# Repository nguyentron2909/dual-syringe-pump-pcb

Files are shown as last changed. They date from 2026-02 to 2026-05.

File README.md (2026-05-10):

# Dual Syringe Pump Controller (ESP32 + TMC2209)

This repository contains the KiCad hardware design for a compact, battery-powered dual stepper motor controller. Designed around the **ESP32-WROOM-32** for wireless control and **TMC2209** silent stepper drivers, this board is optimized for high-precision multi-channel micropump systems and drug delivery applications.

## 🛠 Hardware Architecture

The project is divided into three main functional blocks:

### 1. Power Management & Charging
A robust power subsystem designed to handle both wall power and battery operation, ensuring uninterrupted dispensing.
* **Charging:** Integrated **TP5100** battery charger for 2S Li-ion setups.
* **Regulation:** * **Buck Converter (LM2596):** Stepping down input voltage to 5V for logic.
    * **LDO (AMS1117-3.3):** Providing stable 3.3V for the ESP32 and sensors.
    * **Dual Boost Converters (XL6009):** Independent 12V rails (`+12V_1` and `+12V_2`) to power the stepper drivers, allowing for high-torque performance even on battery power.

### 2. Main Control & Interface
The logic center of the board, featuring:
* **MCU:** ESP32-WROOM-32 with USB-C programming via **CH340C** and an auto-reset circuit.
* **Position Feedback:** Support for dual **AS5600** magnetic encoders via I2C for closed-loop monitoring and exact position tracking.
* **User Interface:** Headers for an external screen, status LEDs, and additional tactile buttons.

### 3. Stepper Driver Stage
High-performance motor control featuring:
* **Drivers:** Dual **TMC2209-LA** drivers (U6 & U7).
* **Communication:** UART interface mapped to the ESP32 for advanced configuration (StealthChop, StallGuard, dynamic current limits).
* **Optimization:** Support for hardware-level current sensing. *(Note: RS resistors should be desoldered from the current sensing module for better performance, as noted in the schematic).*

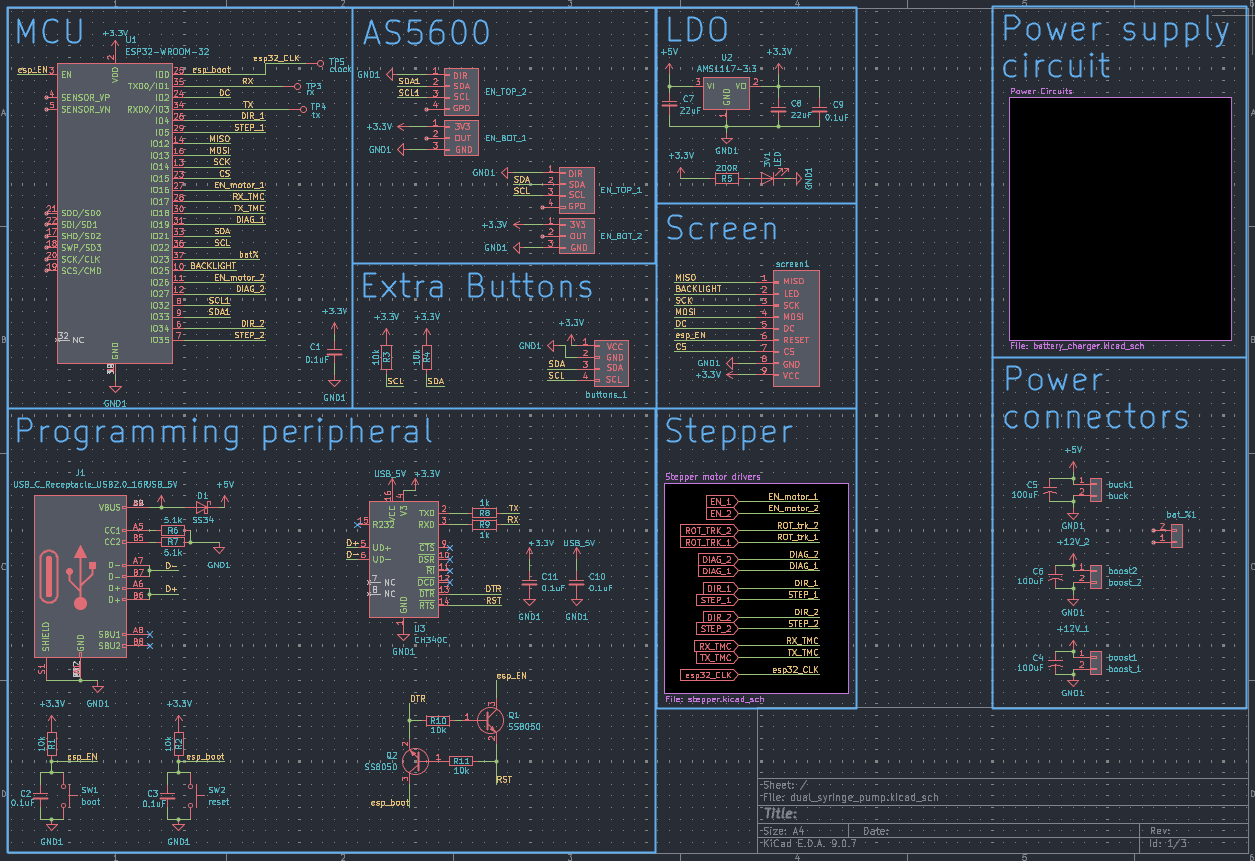
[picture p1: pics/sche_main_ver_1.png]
Control schematics

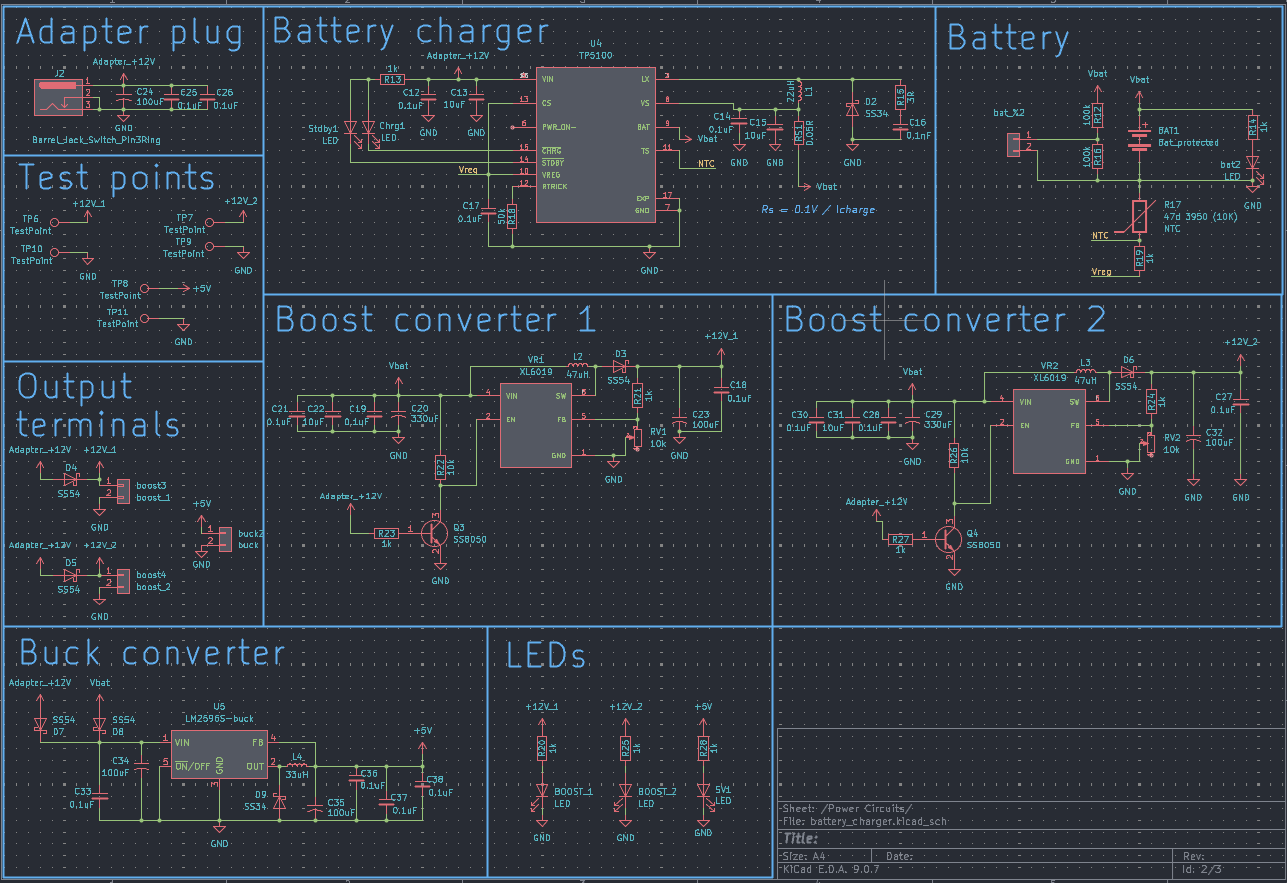
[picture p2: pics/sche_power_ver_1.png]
Power circuits

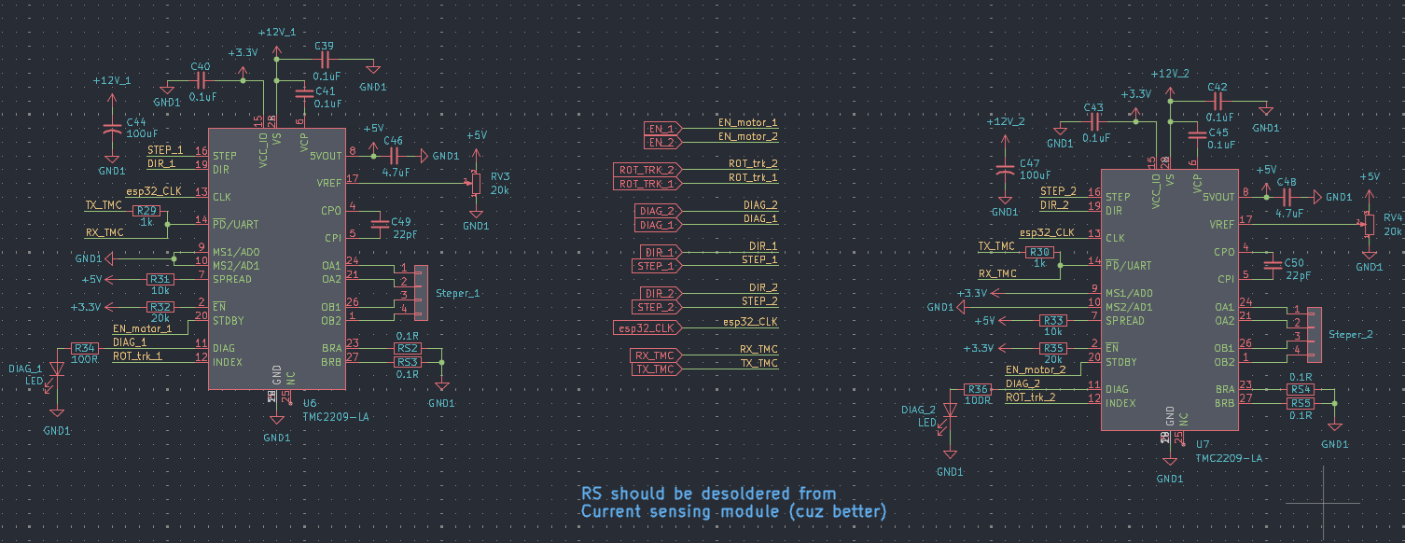
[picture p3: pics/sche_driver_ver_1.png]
drivers

---

## 📋 Key Specifications

| Component | Specification |
| :--- | :--- |
| **Microcontroller** | ESP32-WROOM-32 (Wi-Fi/BT) |
| **Stepper Drivers** | 2x TMC2209 (SilentStepStick style) |
| **Input Voltage** | +12V Adapter or 2S Li-ion Battery |
| **Logic Voltage** | 3.3V and 5V |
| **Sensors** | 2x AS5600 Magnetic Encoders |
| **USB Interface** | USB-C (CH340C) |

---

## 📂 PCB layout
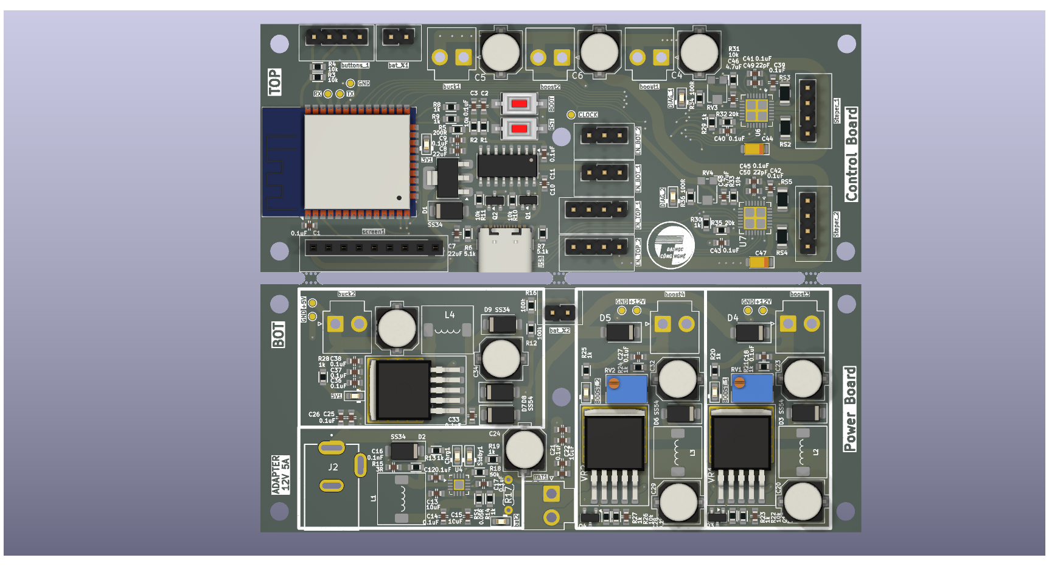
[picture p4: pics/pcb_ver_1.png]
PCB layout

---

## 📝 Design Notes

* **Current Sensing:** Ensure you desolder the RS resistors from the driver modules if you are using an external current sensing setup to avoid interference.
* **Thermal Management:** Provide adequate cooling (heatsinks/airflow) for the XL6009 boost converters and TMC2209 drivers if running the stepper motors at high continuous currents.
* **Big thanks to google gemini for writting this for me :D

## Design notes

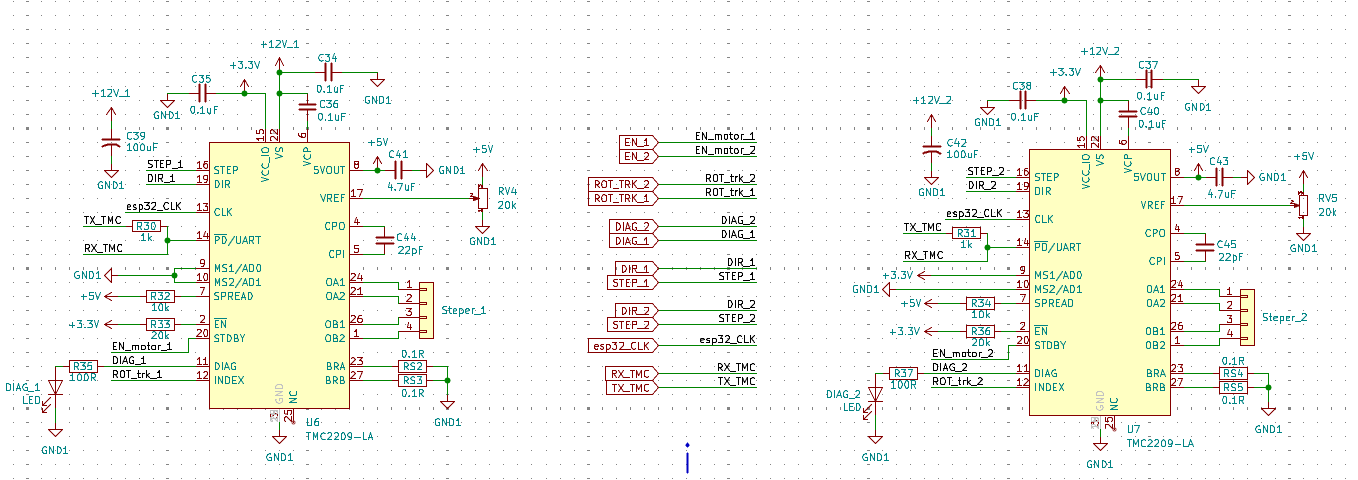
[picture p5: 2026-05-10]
pics/Screenshot 2026-04-07 160638.png

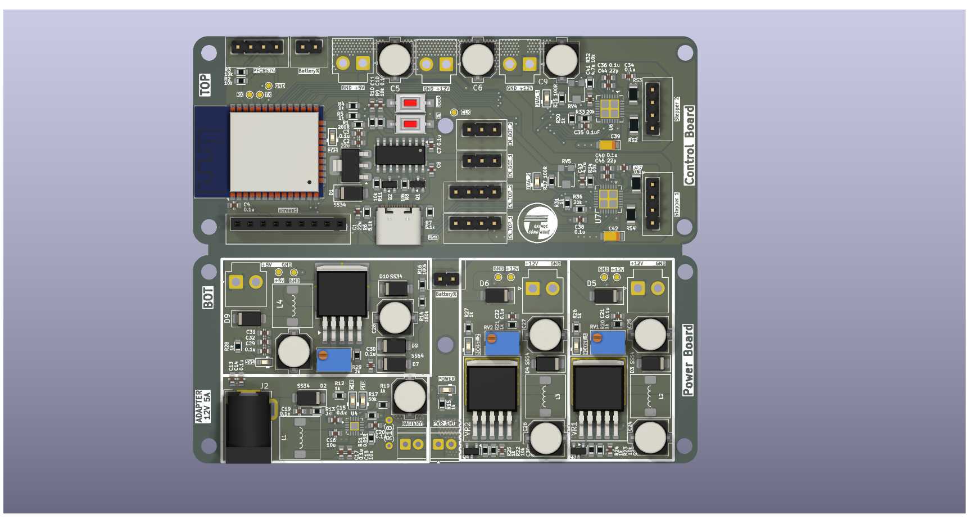
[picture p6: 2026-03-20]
pics/pcb_ver_2.png

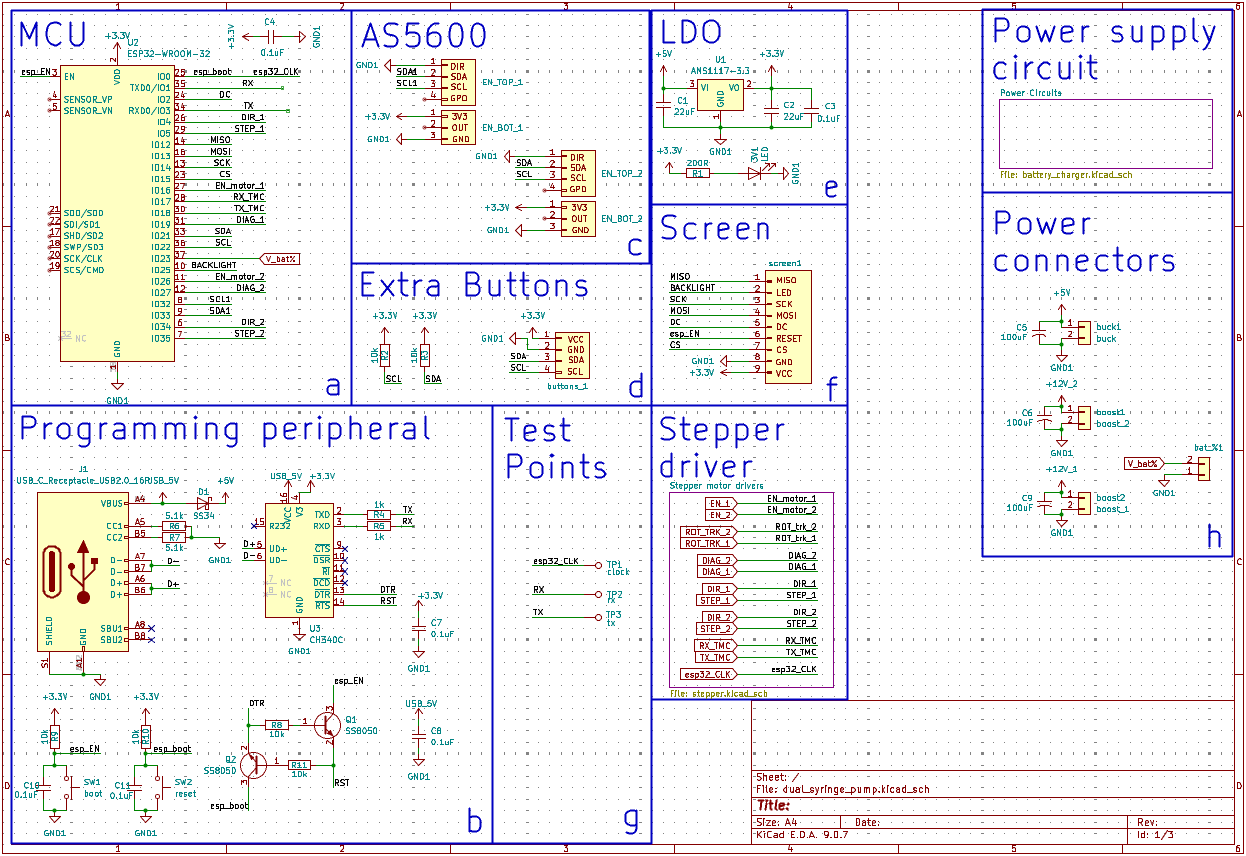
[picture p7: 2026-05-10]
pics/Screenshot 2026-04-07 160020.png

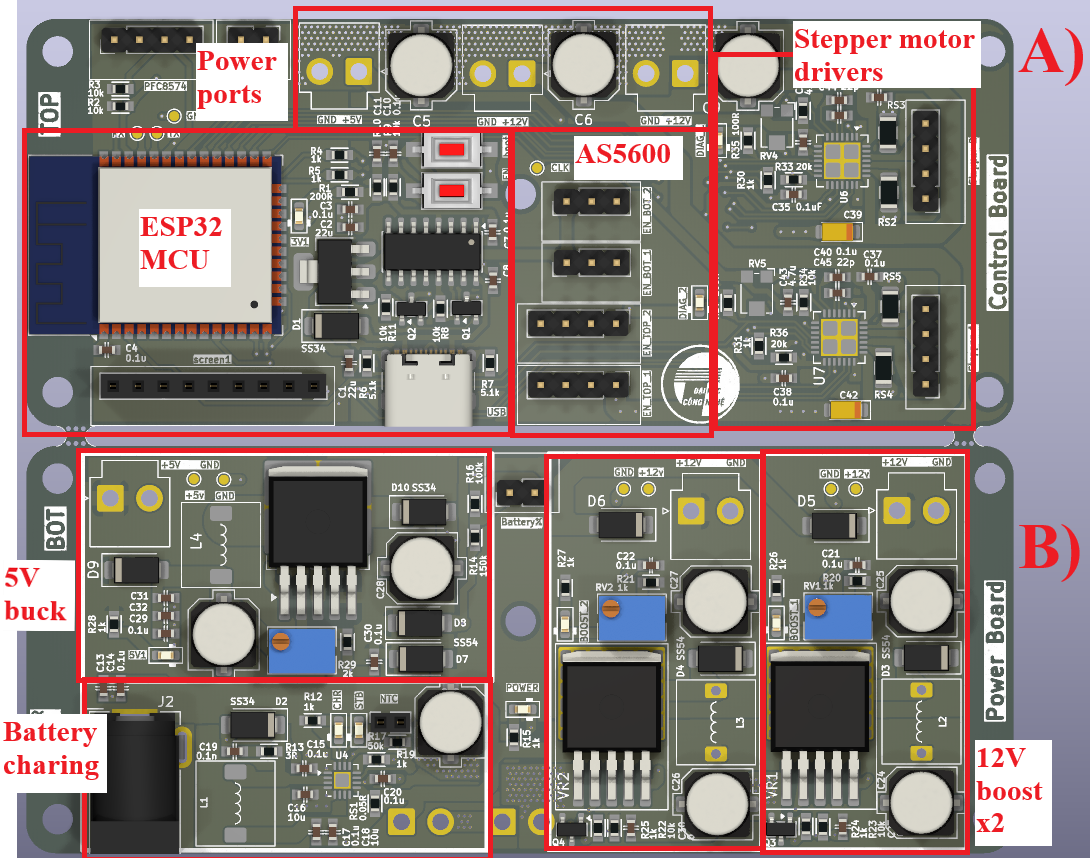
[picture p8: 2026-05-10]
pics/dual_syringe_pump.png

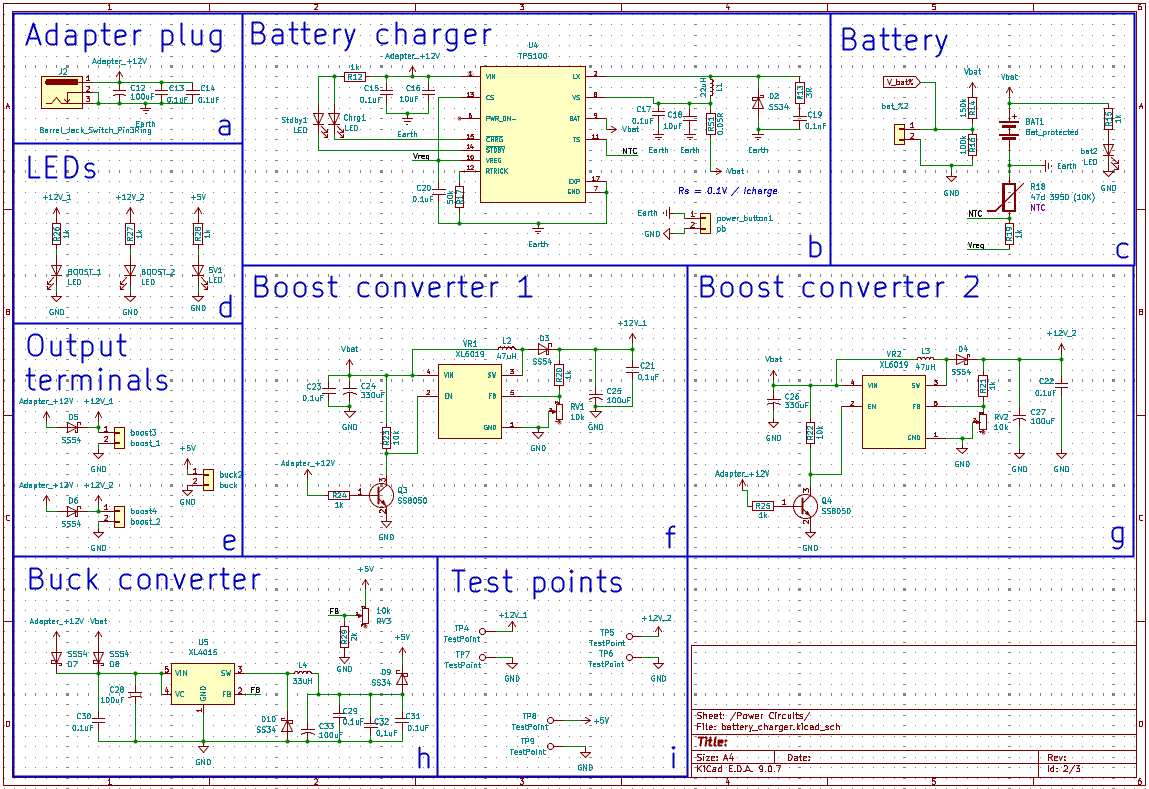
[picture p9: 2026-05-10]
pics/Screenshot 2026-04-07 150947.png

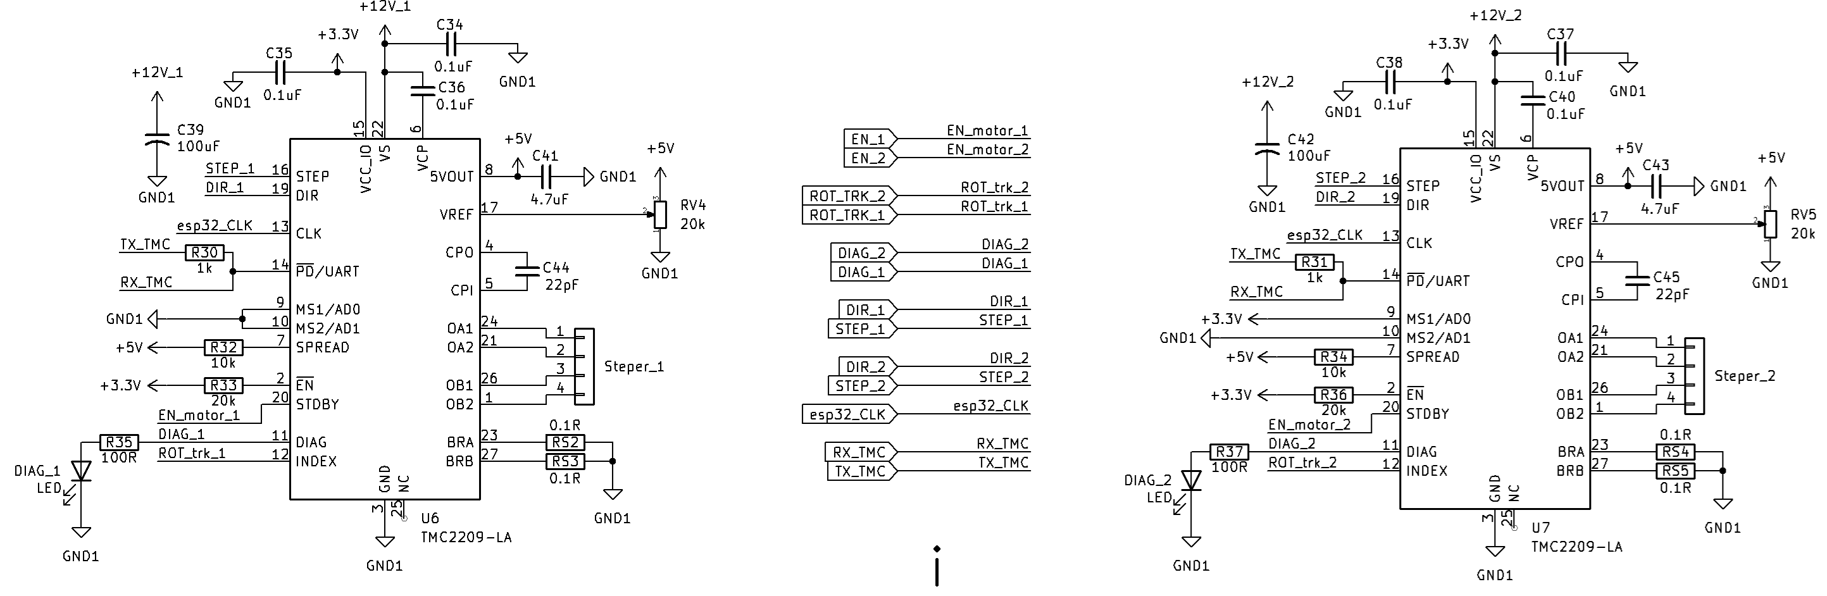
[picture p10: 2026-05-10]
pics/bruh.png

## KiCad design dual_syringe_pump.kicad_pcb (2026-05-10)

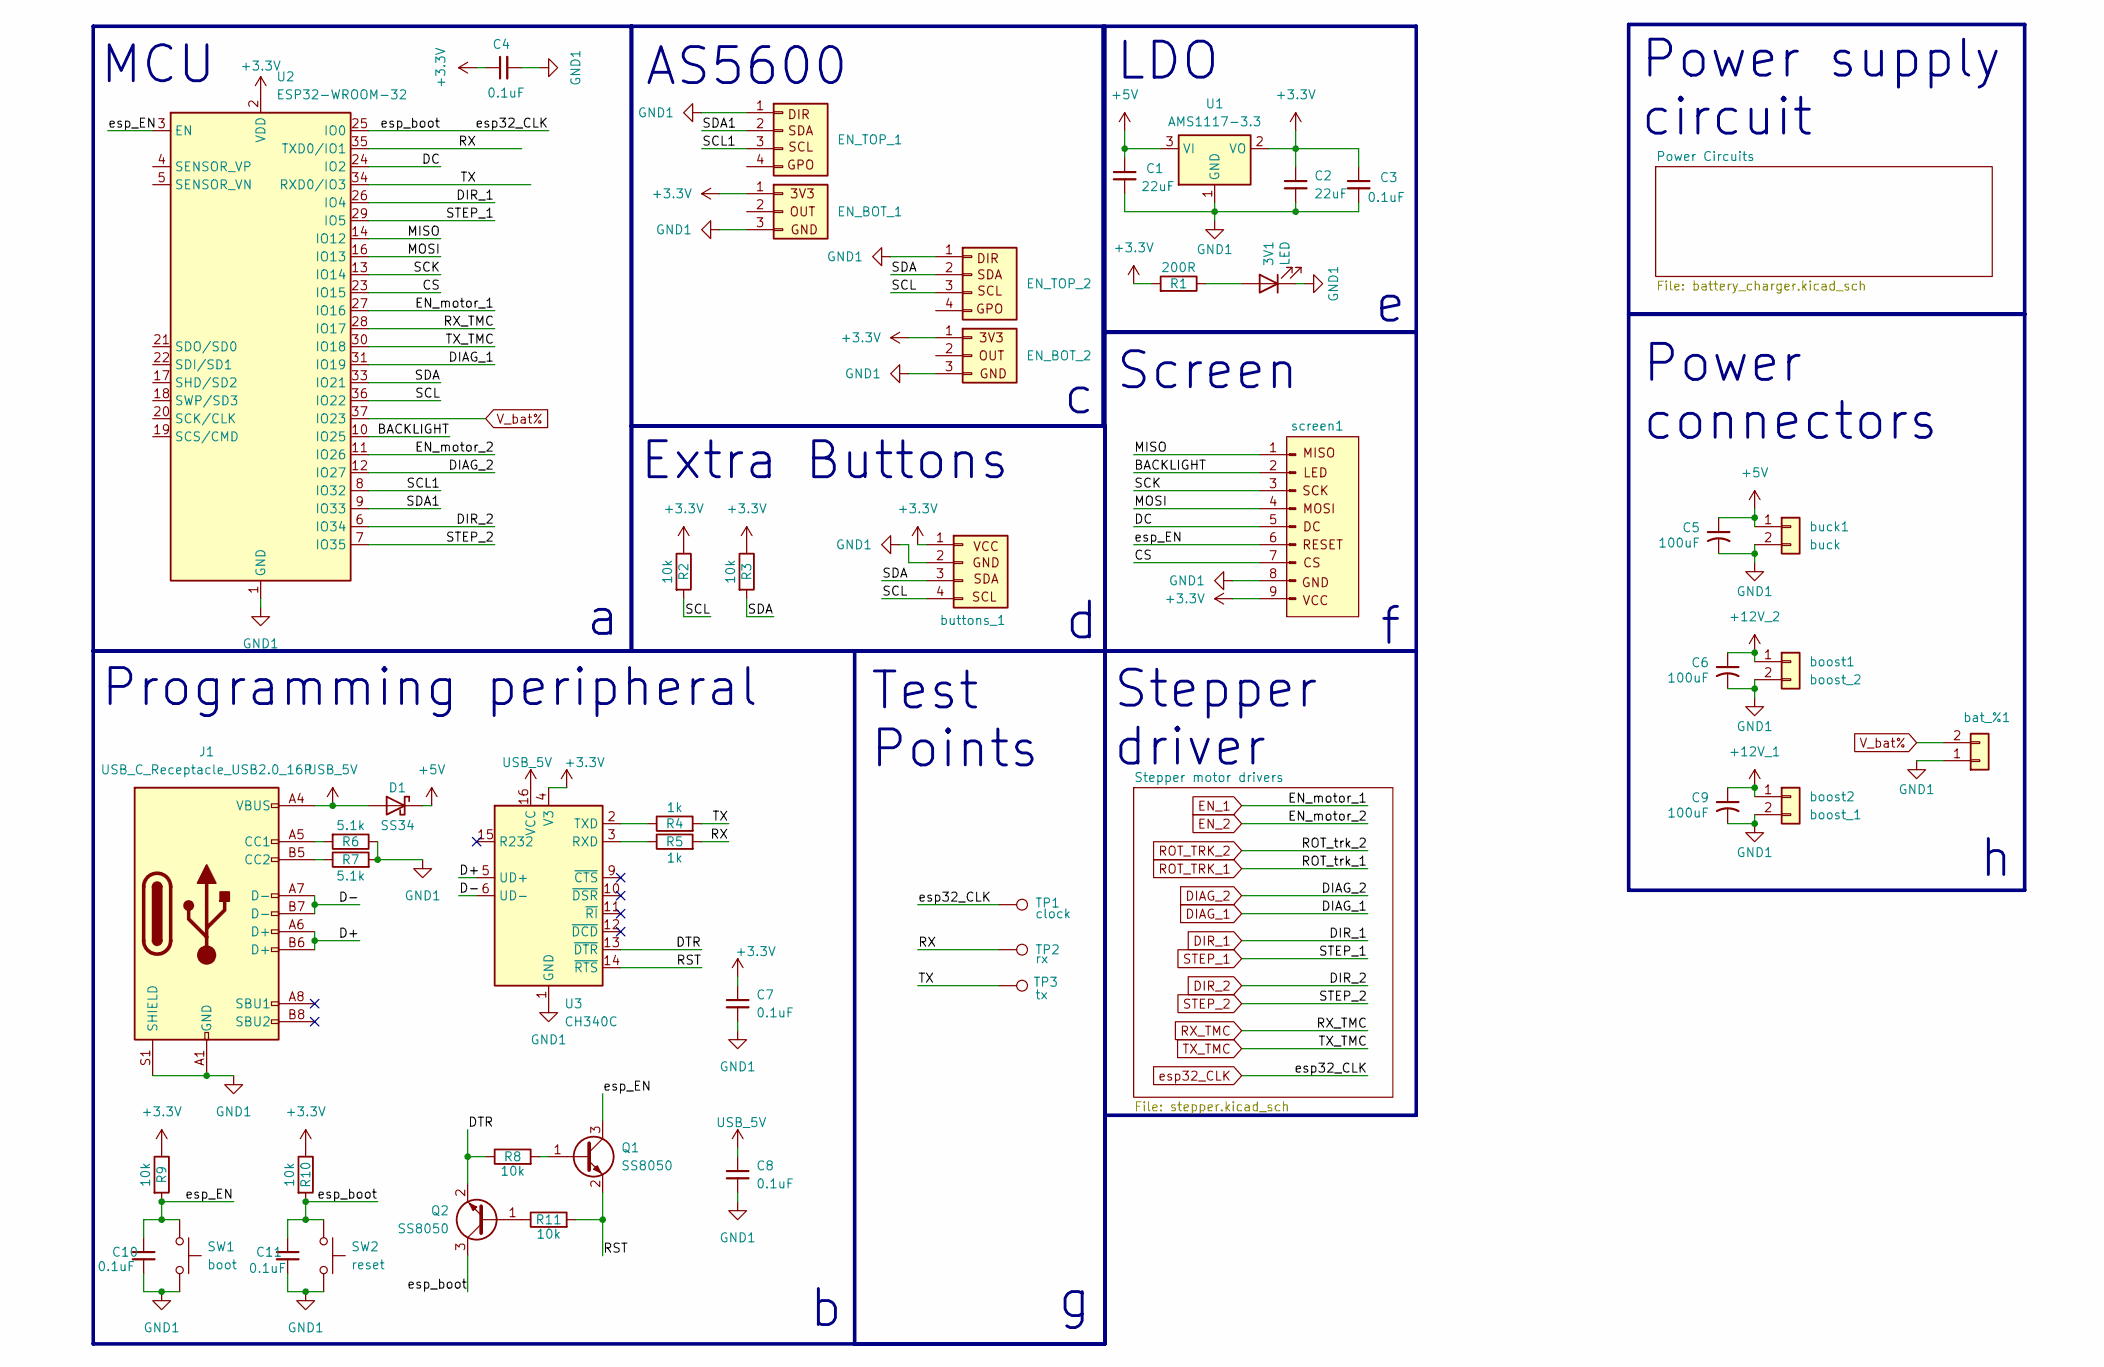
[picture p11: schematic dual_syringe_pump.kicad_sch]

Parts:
3V1: LED; LED_0603_1608Metric_Pad1.05x0.95mm
C1, C2: 22uF; C_0603
C3, C4, C7, C8, C10, C11: 0.1uF; C_0603
C5, C6, C9: 100uF; C_Elec_6.3x7.7
D1: SS34; D_SMA
EN_BOT_1, EN_BOT_2: Conn_01x03; PinHeader_1x03_P2.54mm_Vertical
EN_TOP_1, EN_TOP_2: Conn_01x04; PinHeader_1x04_P2.54mm_Vertical; Part Number 1-0401FBV0T
J1: USB_C_Receptacle_USB2.0_16P; USB_C_Receptacle_GCT_USB4105-xx-A_16P_TopMnt_Horizontal
Q1, Q2: SS8050; SOT-23
R1: 200R; R_0603
R2, R3, R8, R9, R10, R11: 10k; R_0603
R4, R5: 1k; R_0603
R6, R7: 5.1k; R_0603
SW1: boot; SW_SPST_CK_RS282G05A3
SW2: reset; SW_SPST_CK_RS282G05A3
TP1: clock; TestPoint_Pad_D1.0mm
TP2: rx; TestPoint_Pad_D1.0mm
TP3: tx; TestPoint_Pad_D1.0mm
U1: AMS1117-3.3; SOT-223-3_TabPin2
U2: ESP32-WROOM-32
U3: CH340C; SOIC-16_3.9x9.9mm_P1.27mm
bat_%1: battery _percentage; PinHeader_1x02_P2.54mm_Vertical; Part Number 1-0201FBV0T
boost1: boost_2; JST_VH_B2P-VH-B_1x02_P3.96mm_Vertical; Part Number 1-0201FBV0T
boost2: boost_1; JST_VH_B2P-VH-B_1x02_P3.96mm_Vertical; Part Number 1-0201FBV0T
buck1: buck; JST_VH_B2P-VH-B_1x02_P3.96mm_Vertical; Part Number 1-0201FBV0T
buttons_1: Conn_01x04; PinHeader_1x04_P2.54mm_Vertical; Part Number 1-0401FBV0T
screen1: Conn_01x09_Pin; PinSocket_1x09_P2.54mm_Vertical

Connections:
+3.3V: C2.1, C3.1, C4.1, C7.1, EN_BOT_1.1, EN_BOT_2.1, R1.2, R2.1, R3.1, R9.1, R10.1, U1.2 (VO), U2.2 (VDD), U3.4 (V3), buttons_1.1, screen1.9; also elsewhere on the board
+5V: C1.1, C5.1, D1.1 (K), U1.3 (VI), buck1.1; also elsewhere on the board
+12V_1: C9.1, boost2.1; also elsewhere on the board
+12V_2: C6.1, boost1.1; also elsewhere on the board
/BACKLIGHT: U2.10 (IO25), screen1.2
/CS: U2.23 (IO15), screen1.7
/D+: J1.A6 (D+), J1.B6 (D+), U3.5 (UD+)
/D-: J1.A7 (D-), J1.B7 (D-), U3.6 (UD-)
/DC: U2.24 (IO2), screen1.5
/DTR: Q2.2 (E), R8.1, U3.13 (~DTR)
/MISO: U2.14 (IO12), screen1.1
/MOSI: U2.16 (IO13), screen1.4
/RST: Q1.2 (E), R11.2, U3.14 (~RTS)
/RX: R5.2, TP2.1 (1_1), U2.35 (TXD0/IO1)
/SCK: U2.13 (IO14), screen1.3
/SCL: EN_TOP_2.3, R2.2, U2.36 (IO22), buttons_1.4
/SCL1: EN_TOP_1.3, U2.8 (IO32)
/SDA: EN_TOP_2.2, R3.2, U2.33 (IO21), buttons_1.3
/SDA1: EN_TOP_1.2, U2.9 (IO33)
/TX: R4.2, TP3.1 (1_1), U2.34 (RXD0/IO3)
/esp_EN: C10.1, Q1.3 (C), R9.2, SW1.1, U2.3 (EN), screen1.6
DIAG_1: U2.31 (IO19); also elsewhere on the board
DIAG_2: U2.12 (IO27); also elsewhere on the board
DIR_1: U2.26 (IO4); also elsewhere on the board
DIR_2: U2.6 (IO34); also elsewhere on the board
EN_1: U2.27 (IO16); also elsewhere on the board
EN_2: U2.11 (IO26); also elsewhere on the board
GND1: 3V1.1 (K), C1.2, C2.2, C3.2, C4.2, C5.2, C6.2, C7.2, C8.2, C9.2, C10.2, C11.2, EN_BOT_1.3, EN_BOT_2.3, EN_TOP_1.1, EN_TOP_2.1, J1.A1 (GND), J1.A12 (GND), J1.B1 (GND), J1.B12 (GND), J1.S1 (SHIELD), R6.1, R7.2, SW1.2, SW2.2, U1.1 (GND), U2.1 (GND), U2.15 (GND), U2.38 (GND), U2.39 (GND), U3.1 (GND), bat_%1.1, boost1.2, boost2.2, buck1.2, buttons_1.2, screen1.8; also elsewhere on the board
unnamed: 3V1.2 (A), R1.1
unnamed: J1.A5 (CC1), R6.2
unnamed: J1.B5 (CC2), R7.1
unnamed: Q1.1 (B), R8.2
unnamed: Q2.1 (B), R11.1
unnamed: R5.1, U3.3 (RXD)
unnamed: R4.1, U3.2 (TXD)
RX_TMC: U2.28 (IO17); also elsewhere on the board
STEP_1: U2.29 (IO5); also elsewhere on the board
STEP_2: U2.7 (IO35); also elsewhere on the board
TX_TMC: U2.30 (IO18); also elsewhere on the board
USB_5V: C8.1, D1.2 (A), J1.A4 (VBUS), J1.A9 (VBUS), J1.B4 (VBUS), J1.B9 (VBUS), U3.16 (VCC)
V_bat%: U2.37 (IO23), bat_%1.2; also elsewhere on the board
esp32_CLK: C11.1, Q2.3 (C), R10.2, SW2.1, TP1.1 (1_1), U2.25 (IO0); also elsewhere on the board

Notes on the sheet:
Test Points
Power supply circuit
Screen
Programming peripheral
Extra Buttons
LDO
MCU
Stepper driver
AS5600
Power connectors

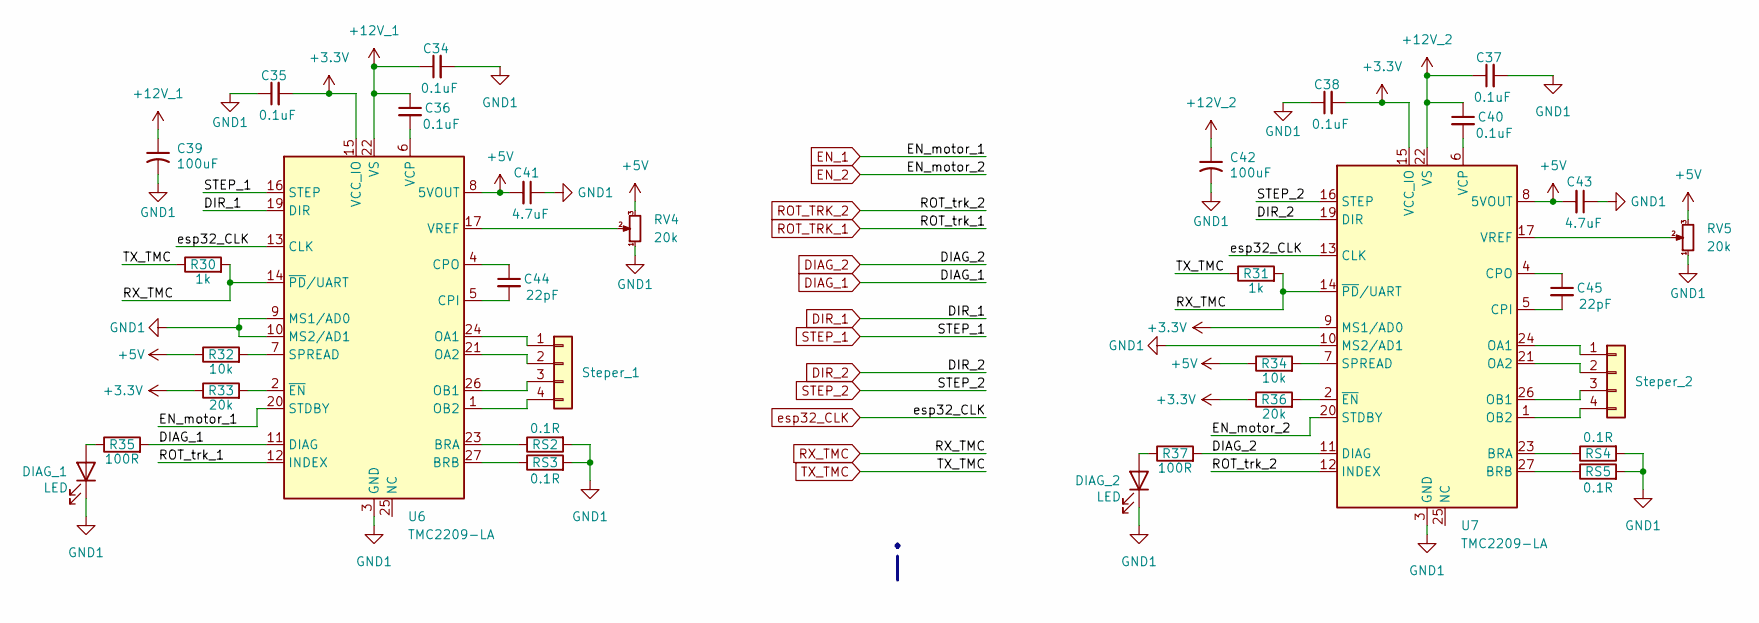
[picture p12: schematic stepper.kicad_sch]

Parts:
C34, C35, C36, C37, C38, C40: 0.1uF; C_0603
C39, C42: 100uF; CP_EIA-3216-12_Kemet-S_HandSolder
C41, C43: 4.7uF; C_0603
C44, C45: 22pF; C_0603
DIAG_1, DIAG_2: LED; LED_0603_1608Metric_Pad1.05x0.95mm
R30, R31: 1k; R_0603
R32, R34: 10k; R_0603
R33, R36: 20k; R_0603
R35, R37: 100R; R_0603
RS2, RS3, RS4, RS5: 0.1R; R_1206_3216Metric
RV4, RV5: 20k; Potentiometer_Bourns_TC33X_Vertical
Steper_1, Steper_2: Conn_01x04; PinHeader_1x04_P2.54mm_Vertical; Part Number 1-0401FBV0T
U6, U7: TMC2209-LA; VQFN-28-1EP_5x5mm_P0.5mm_EP3.7x3.7mm_ThermalVias

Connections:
+3.3V: C35.2, C38.2, R33.1, R36.1, U6.15 (VCC_IO), U7.9 (MS1/AD0), U7.15 (VCC_IO); also elsewhere on the board
+5V: C41.2, C43.2, R32.1, R34.1, RV4.3, RV5.3, U6.8 (5VOUT), U7.8 (5VOUT); also elsewhere on the board
+12V_1: C34.1, C36.1, C39.1, U6.22 (VS), U6.28 (VS); also elsewhere on the board
+12V_2: C37.1, C40.1, C42.1, U7.22 (VS), U7.28 (VS); also elsewhere on the board
DIAG_1: R35.2, U6.11 (DIAG); also elsewhere on the board
DIAG_2: R37.2, U7.11 (DIAG); also elsewhere on the board
DIR_1: U6.19 (DIR); also elsewhere on the board
DIR_2: U7.19 (DIR); also elsewhere on the board
EN_1: U6.20 (STDBY); also elsewhere on the board
EN_2: U7.20 (STDBY); also elsewhere on the board
GND1: C34.2, C35.1, C37.2, C38.1, C39.2, C41.1, C42.2, C43.1, DIAG_1.1 (K), DIAG_2.1 (K), RS2.2, RS3.2, RS4.2, RS5.2, RV4.1, RV5.1, U6.3 (GND), U6.9 (MS1/AD0), U6.10 (MS2/AD1), U6.18 (GND), U6.29 (GND), U7.3 (GND), U7.10 (MS2/AD1), U7.18 (GND), U7.29 (GND); also elsewhere on the board
unnamed: DIAG_1.2 (A), R35.1
unnamed: DIAG_2.2 (A), R37.1
unnamed: Steper_1.1, U6.24 (OA1)
unnamed: Steper_1.2, U6.21 (OA2)
unnamed: Steper_1.3, U6.26 (OB1)
unnamed: Steper_1.4, U6.1 (OB2)
unnamed: Steper_2.1, U7.24 (OA1)
unnamed: Steper_2.2, U7.21 (OA2)
unnamed: Steper_2.3, U7.26 (OB1)
unnamed: Steper_2.4, U7.1 (OB2)
unnamed: RS2.1, U6.23 (BRA)
unnamed: RS3.1, U6.27 (BRB)
unnamed: C44.2, U6.5 (CPI)
unnamed: C44.1, U6.4 (CPO)
unnamed: R32.2, U6.7 (SPREAD)
unnamed: C36.2, U6.6 (VCP)
unnamed: RV4.2, U6.17 (VREF)
unnamed: R33.2, U6.2 (~EN)
unnamed: RS4.1, U7.23 (BRA)
unnamed: RS5.1, U7.27 (BRB)
unnamed: C45.2, U7.5 (CPI)
unnamed: C45.1, U7.4 (CPO)
unnamed: R34.2, U7.7 (SPREAD)
unnamed: C40.2, U7.6 (VCP)
unnamed: RV5.2, U7.17 (VREF)
unnamed: R36.2, U7.2 (~EN)
ROT_TRK_1: U6.12 (INDEX)
ROT_TRK_2: U7.12 (INDEX)
RX_TMC: R30.2, R31.2, U6.14 (~PD/UART), U7.14 (~PD/UART); also elsewhere on the board
STEP_1: U6.16 (STEP); also elsewhere on the board
STEP_2: U7.16 (STEP); also elsewhere on the board
TX_TMC: R30.1, R31.1; also elsewhere on the board
esp32_CLK: U6.13 (CLK), U7.13 (CLK); also elsewhere on the board

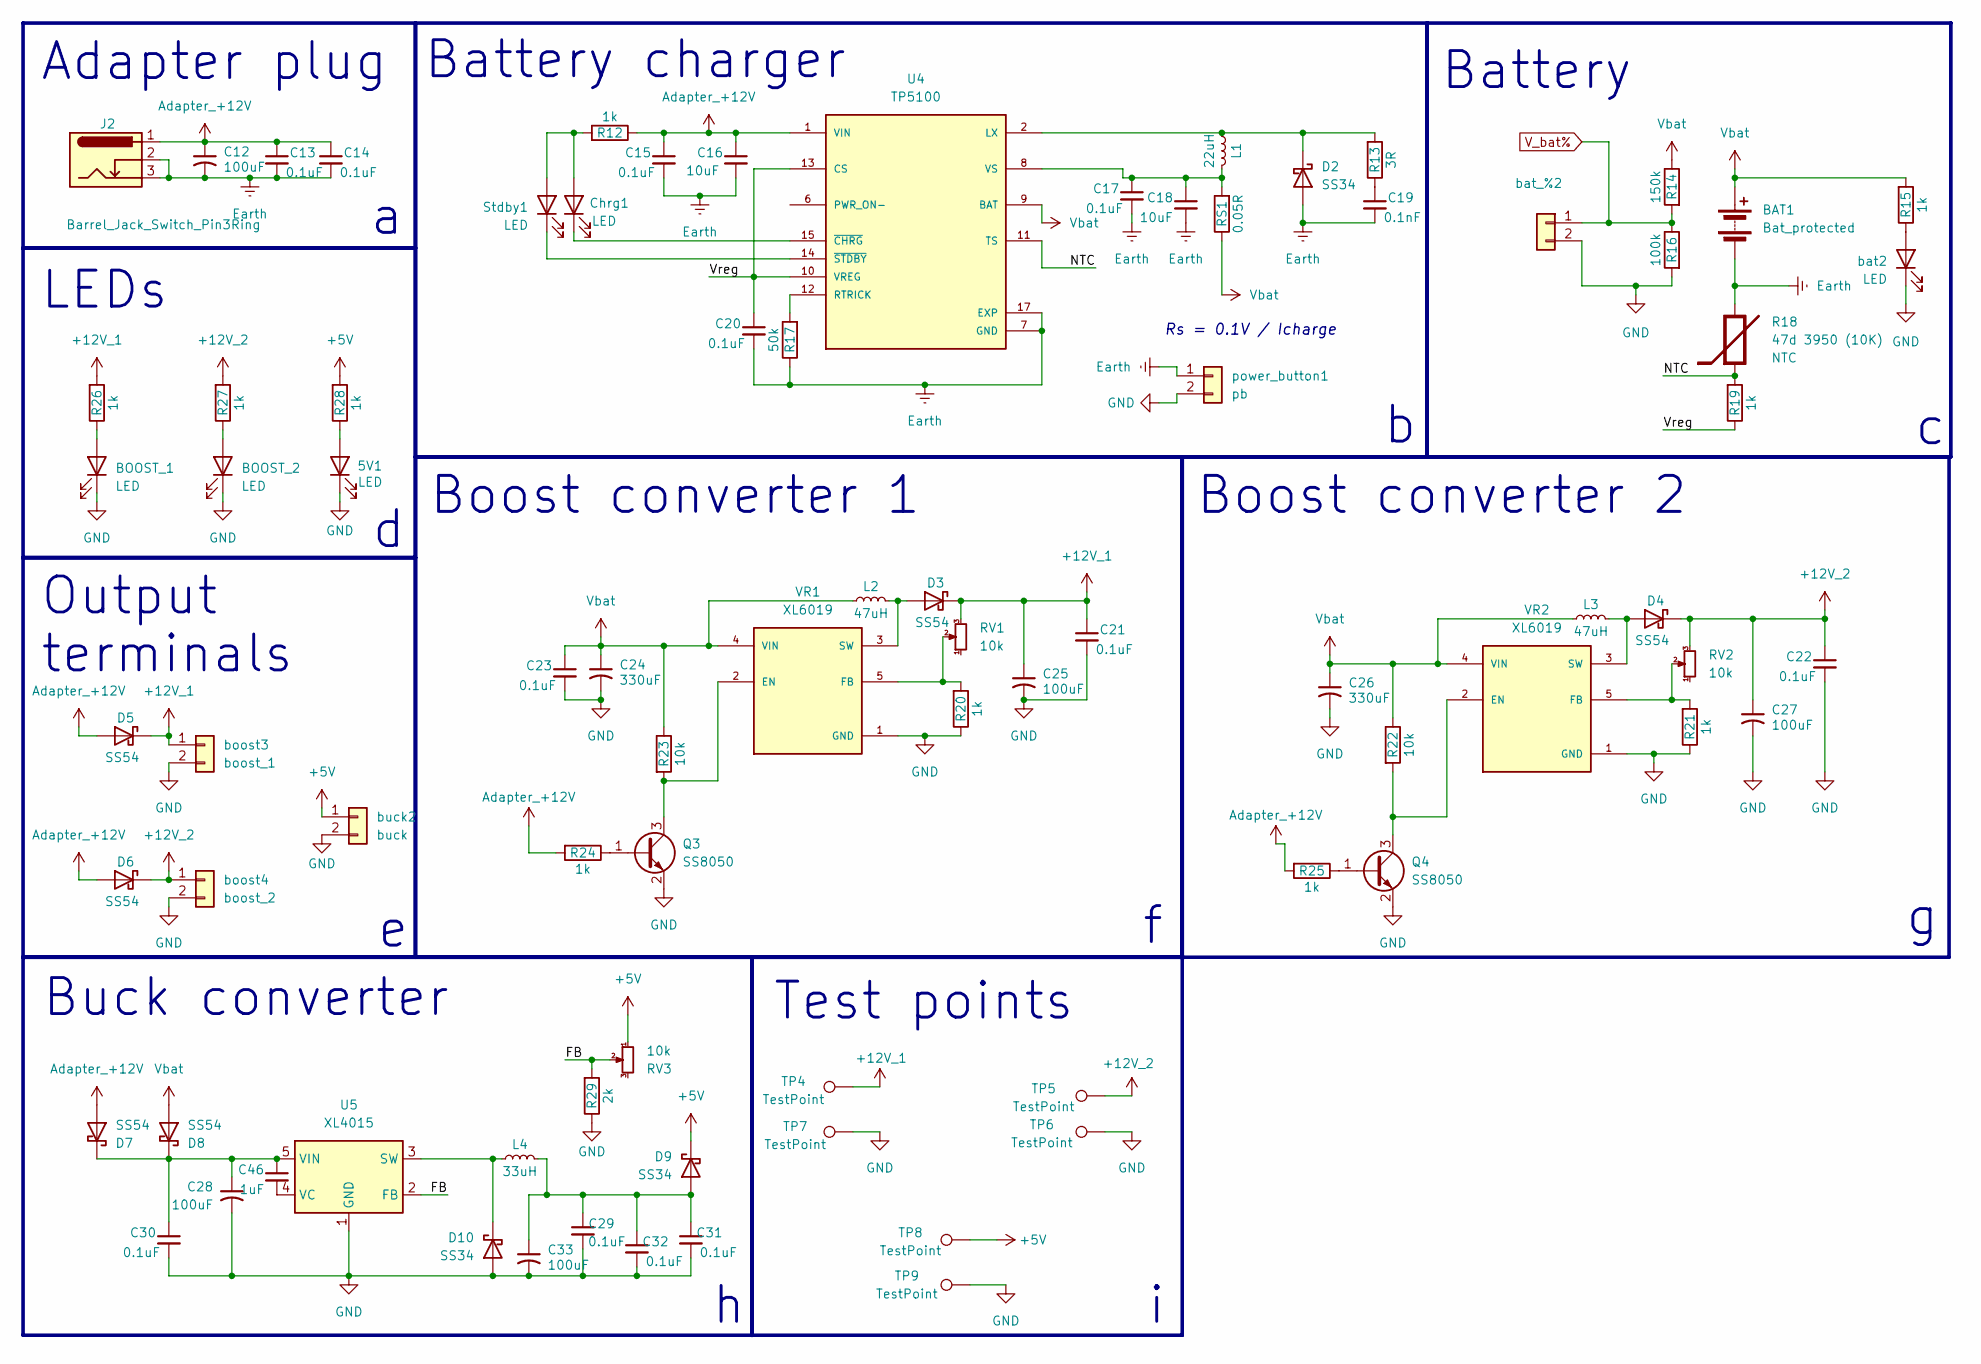
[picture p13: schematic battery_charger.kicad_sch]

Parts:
5V1: LED; LED_0603_1608Metric_Pad1.05x0.95mm
BAT1: Bat_protected; JST_VH_B2P-VH-B_1x02_P3.96mm_Vertical
BOOST_1, BOOST_2: LED; LED_0603_1608Metric_Pad1.05x0.95mm
C12, C28, C33: 100uF; C_Elec_6.3x7.7
C13, C14, C15, C17, C20, C21, C22, C23, C29, C30, C31, C32: 0.1uF; C_0603
C16, C18: 10uF; C_0603
C19: 0.1nF; C_0603
C24, C26: 330uF; C_Elec_6.3x7.7
C25, C27: 100uF; C_Elec_8x10.2
C46: 1uF; C_0603
Chrg1: LED; LED_0603_1608Metric_Pad1.05x0.95mm
D2, D9, D10: SS34; D_SMA
D3, D4: SS54; D_SMC
D5, D6, D7, D8: SS54; D_SMA
J2: Barrel_Jack_Switch_Pin3Ring; BarrelJack_GCT_DCJ200-10-A_Horizontal
L1: 22uH; L_7.3x7.3_H3.5
L2, L3: 47uH; L_SXN_SMDRI124
L4: 33uH; L_SXN_SMDRI124
Q3, Q4: SS8050; SOT-23
R12, R15, R19, R20, R21, R24, R25, R26, R27, R28: 1k; R_0603
R13: 3R; R_0603
R14: 150k; R_0603
R16: 100k; R_0603
R17: 50k; R_0603
R18: 47d 3950 (10K); PinHeader_1x02_P2.00mm_Vertical; Rating NTC
R22, R23: 10k; R_0603
R29: 2k; R_0603
RS1: 0.05R; R_1206_3216Metric
RV1, RV2, RV3: 10k; Potentiometer_Bourns_TC33X_Vertical
Stdby1: LED; LED_0603_1608Metric_Pad1.05x0.95mm
TP4, TP5, TP6, TP7, TP8, TP9: TestPoint; TestPoint_Pad_D1.0mm
U4: TP5100; QFN-16-1EP_4x4mm_P0.65mm_EP2.15x2.15mm_ThermalVias; PARTREV 2.3
U5: XL4015; TO-263-5_TabPin3
VR1, VR2: XL6019; TO-263-5_TabPin6_ThermalVias; PARTREV 1.1
bat2: LED; LED_0603_1608Metric_Pad1.05x0.95mm
bat_%2: battery _percentage; PinHeader_1x02_P2.54mm_Vertical; Part Number 1-0201FBV0T
boost3: boost_1; JST_VH_B2P-VH-B_1x02_P3.96mm_Vertical; Part Number 1-0201FBV0T
boost4: boost_2; JST_VH_B2P-VH-B_1x02_P3.96mm_Vertical; Part Number 1-0201FBV0T
buck2: buck; JST_VH_B2P-VH-B_1x02_P3.96mm_Vertical; Part Number 1-0201FBV0T
power_button1: pb; JST_VH_B2P-VH-B_1x02_P3.96mm_Vertical; Part Number 1-0201FBV0T

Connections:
+5V: D9.1 (K), R28.2, RV3.1, TP8.1 (1_1), buck2.1; also elsewhere on the board
+12V_1: C21.1, C25.1, D3.1 (K), D5.1 (K), R26.2, RV1.3, TP4.1 (1_1), boost3.1; also elsewhere on the board
+12V_2: C22.1, C27.1, D4.1 (K), D6.1 (K), R27.2, RV2.3, TP5.1 (1_1), boost4.1; also elsewhere on the board
/Power Circuits/FB: R29.2, RV3.2, U5.2 (FB)
/Power Circuits/NTC: R18.2 (-), R19.2, U4.11 (TS); also elsewhere on the board
/Power Circuits/Vreg: C20.1, R19.1, U4.10 (VREG), U4.13 (CS)
Adapter_+12V: C12.1, C13.1, C14.1, C15.1, C16.1, D5.2 (A), D6.2 (A), D7.2 (A), J2.1, R12.1, R24.2, R25.2, U4.1 (VIN), U4.4 (VIN), U4.5 (VIN), U4.16 (VIN)
Earth: BAT1.2 (-), C12.2, C13.2, C14.2, C15.2, C16.2, C17.2, C18.2, C19.2, C20.2, D2.2 (A), J2.2, J2.3, R17.1, R18.1 (+), U4.7 (GND), U4.17 (EXP), power_button1.1; also elsewhere on the board
GND: 5V1.1 (K), BOOST_1.1 (K), BOOST_2.1 (K), C21.2, C22.2, C23.2, C24.2, C25.2, C26.2, C27.2, C28.2, C29.2, C30.2, C31.2, C32.2, C33.2, D10.2 (A), Q3.2 (E), Q4.2 (E), R16.2, R20.1, R21.1, R29.1, TP6.1 (1_1), TP7.1 (1_1), TP9.1 (1_1), U5.1 (GND), VR1.1 (GND), VR2.1 (GND), bat2.1 (K), bat_%2.2, boost3.2, boost4.2, buck2.2, power_button1.2; also elsewhere on the board
unnamed: 5V1.2 (A), R28.1
unnamed: BOOST_1.2 (A), R26.1
unnamed: BOOST_2.2 (A), R27.1
unnamed: C19.1, R13.1
unnamed: Chrg1.2 (A), R12.2, Stdby1.2 (A)
unnamed: Chrg1.1 (K), U4.15 (~CHRG)
unnamed: D2.1 (K), L1.1, R13.2, U4.2 (LX), U4.3 (LX)
unnamed: D3.2 (A), L2.2, VR1.3 (SW), VR1.6 (SW)
unnamed: D4.2 (A), L3.2, VR2.3 (SW), VR2.6 (SW)
unnamed: C28.1, C30.1, C46.1, D7.1 (K), D8.1 (K), U5.5 (VIN)
unnamed: C29.1, C31.1, C32.1, C33.1, D9.2 (A), L4.2
unnamed: D10.1 (K), L4.1, U5.3 (SW)
unnamed: Q3.1 (B), R24.1
unnamed: Q3.3 (C), R23.2, VR1.2 (EN)
unnamed: Q4.1 (B), R25.1
unnamed: Q4.3 (C), R22.2, VR2.2 (EN)
unnamed: Stdby1.1 (K), U4.14 (~STDBY)
unnamed: R17.2, U4.12 (RTRICK)
unnamed: C17.1, C18.1, L1.2, RS1.2, U4.8 (VS)
unnamed: C46.2, U5.4 (VC)
unnamed: R20.2, RV1.2, VR1.5 (FB)
unnamed: R21.2, RV2.2, VR2.5 (FB)
unnamed: R15.1, bat2.2 (A)
V_bat%: R14.2, R16.1, bat_%2.1; also elsewhere on the board
Vbat: BAT1.1 (+), C23.1, C24.1, C26.1, D8.2 (A), L2.1, L3.1, R14.1, R15.2, R22.1, R23.1, RS1.1, U4.9 (BAT), VR1.4 (VIN), VR2.4 (VIN); also elsewhere on the board

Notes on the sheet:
Buck converter
Battery
Battery charger
Boost converter 2
Output terminals
Test points
Adapter plug
Rs = 0.1V / Icharge
Boost converter 1
LEDs

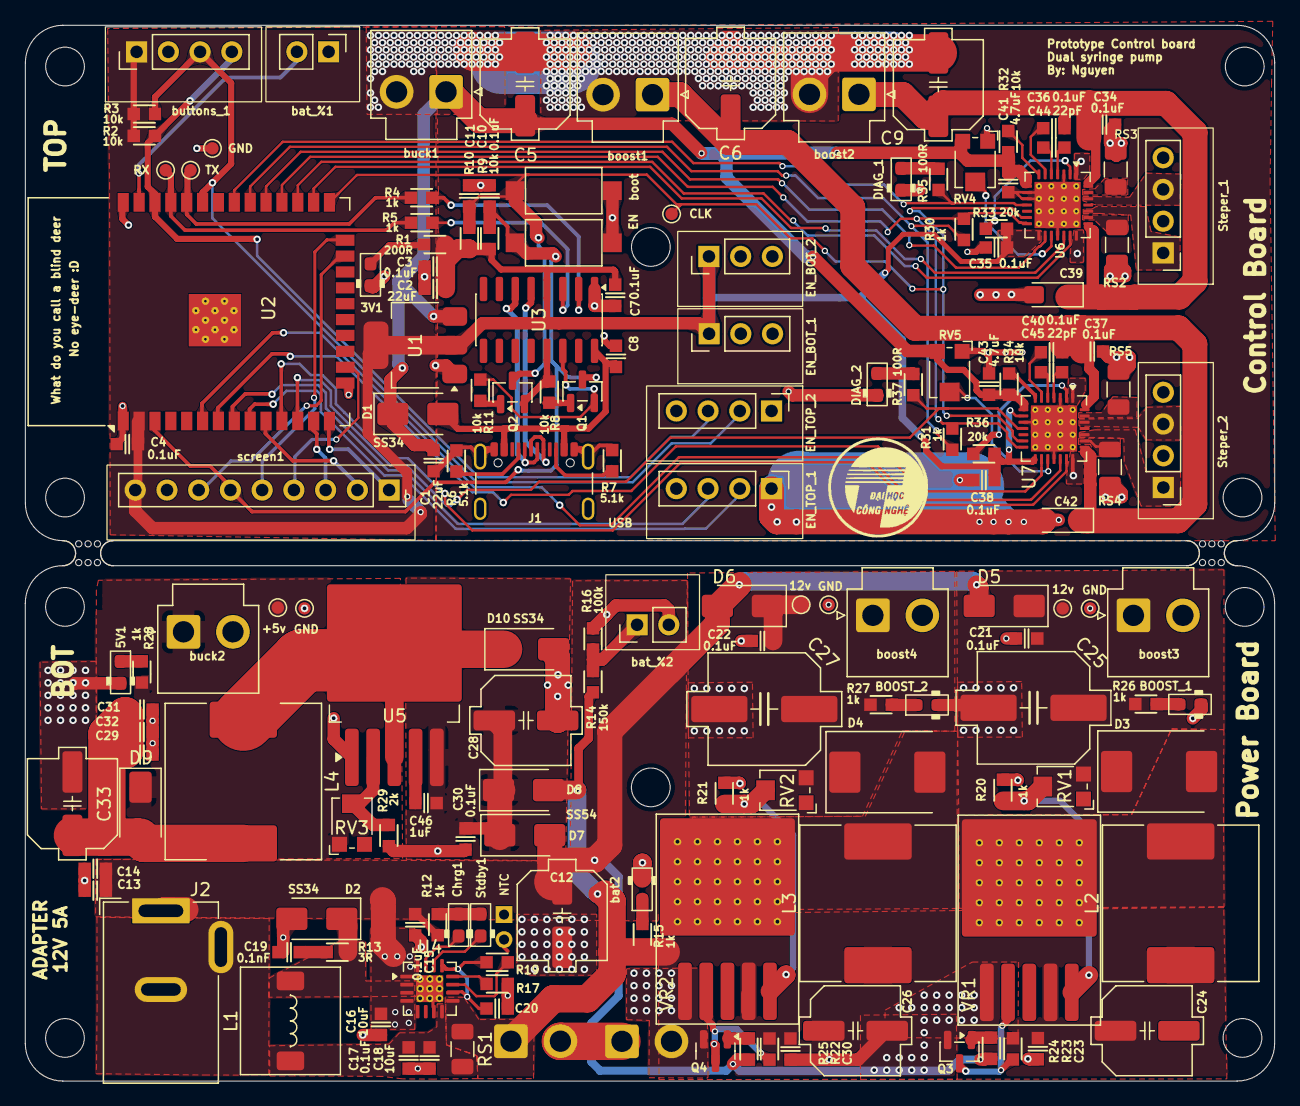
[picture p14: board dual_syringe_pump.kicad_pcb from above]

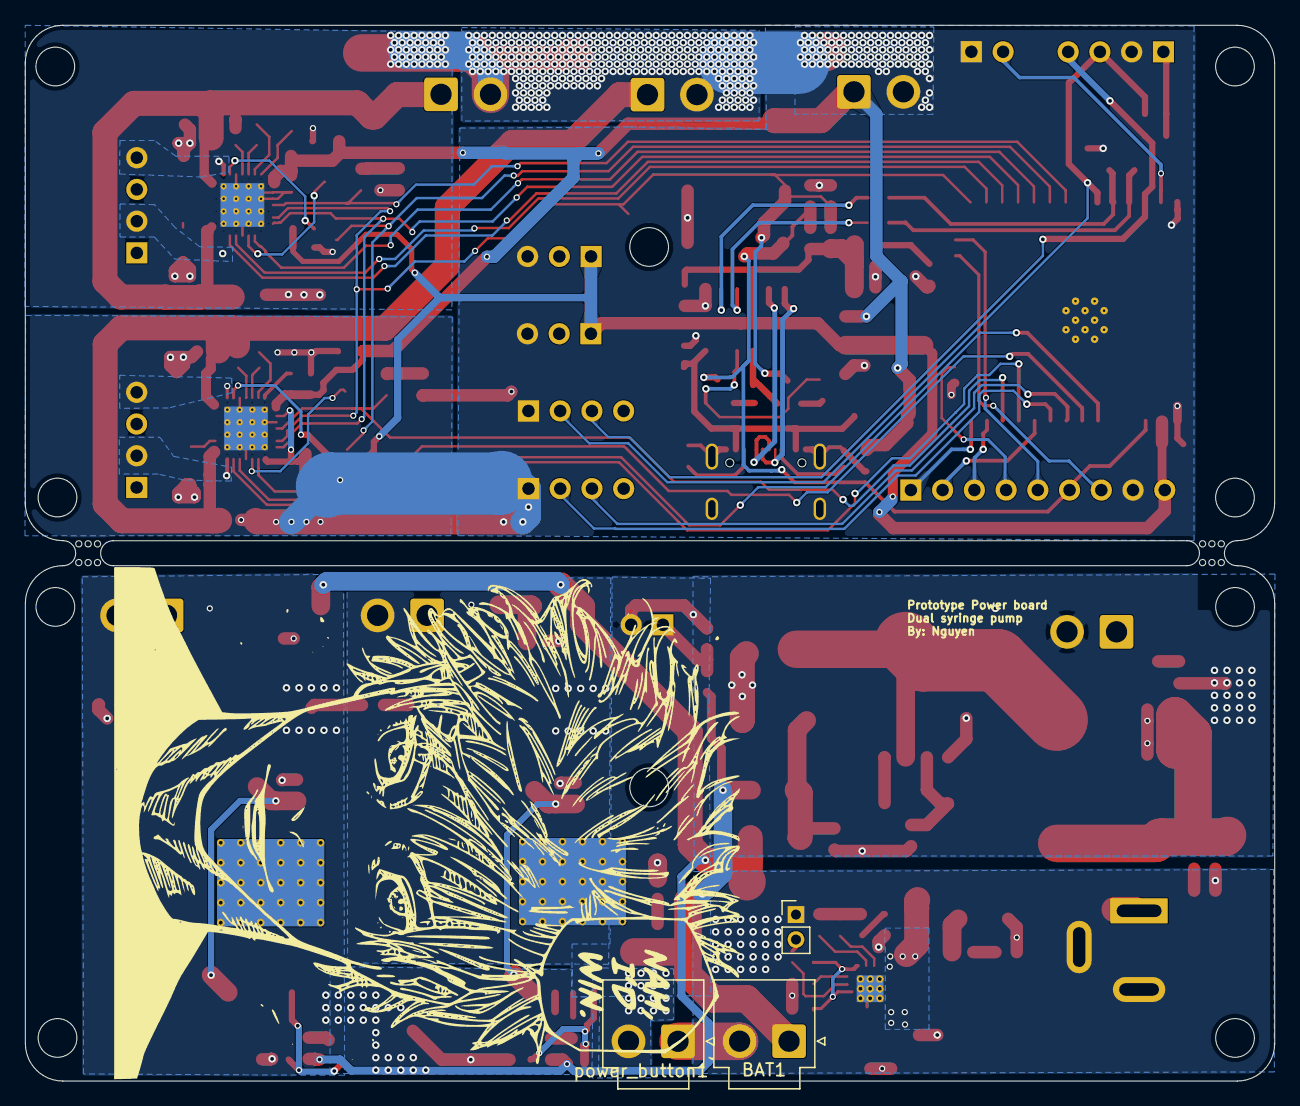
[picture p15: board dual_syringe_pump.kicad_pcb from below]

Board: 2 copper layers, 100.0 x 84.5 mm, 164 parts (3 on the bottom side), 98 nets.

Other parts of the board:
C30#2: 0.1u; C_0603
GND: TestPoint; TestPoint_Pad_D1.0mm
NTC: 47d 3950 (10K); PinHeader_1x02_P2.00mm_Vertical
mouse-bite-2mm-slot, mouse-bite-2mm-slot#2: VAL**; mouse-bite-2mm-slot

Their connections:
/Power Circuits/NTC: NTC.2 (-); also elsewhere on the board
Earth: NTC.1 (+); also elsewhere on the board
GND: C30#2.2; also elsewhere on the board
GND1: GND.1; also elsewhere on the board
Vbat: C30#2.1; also elsewhere on the board

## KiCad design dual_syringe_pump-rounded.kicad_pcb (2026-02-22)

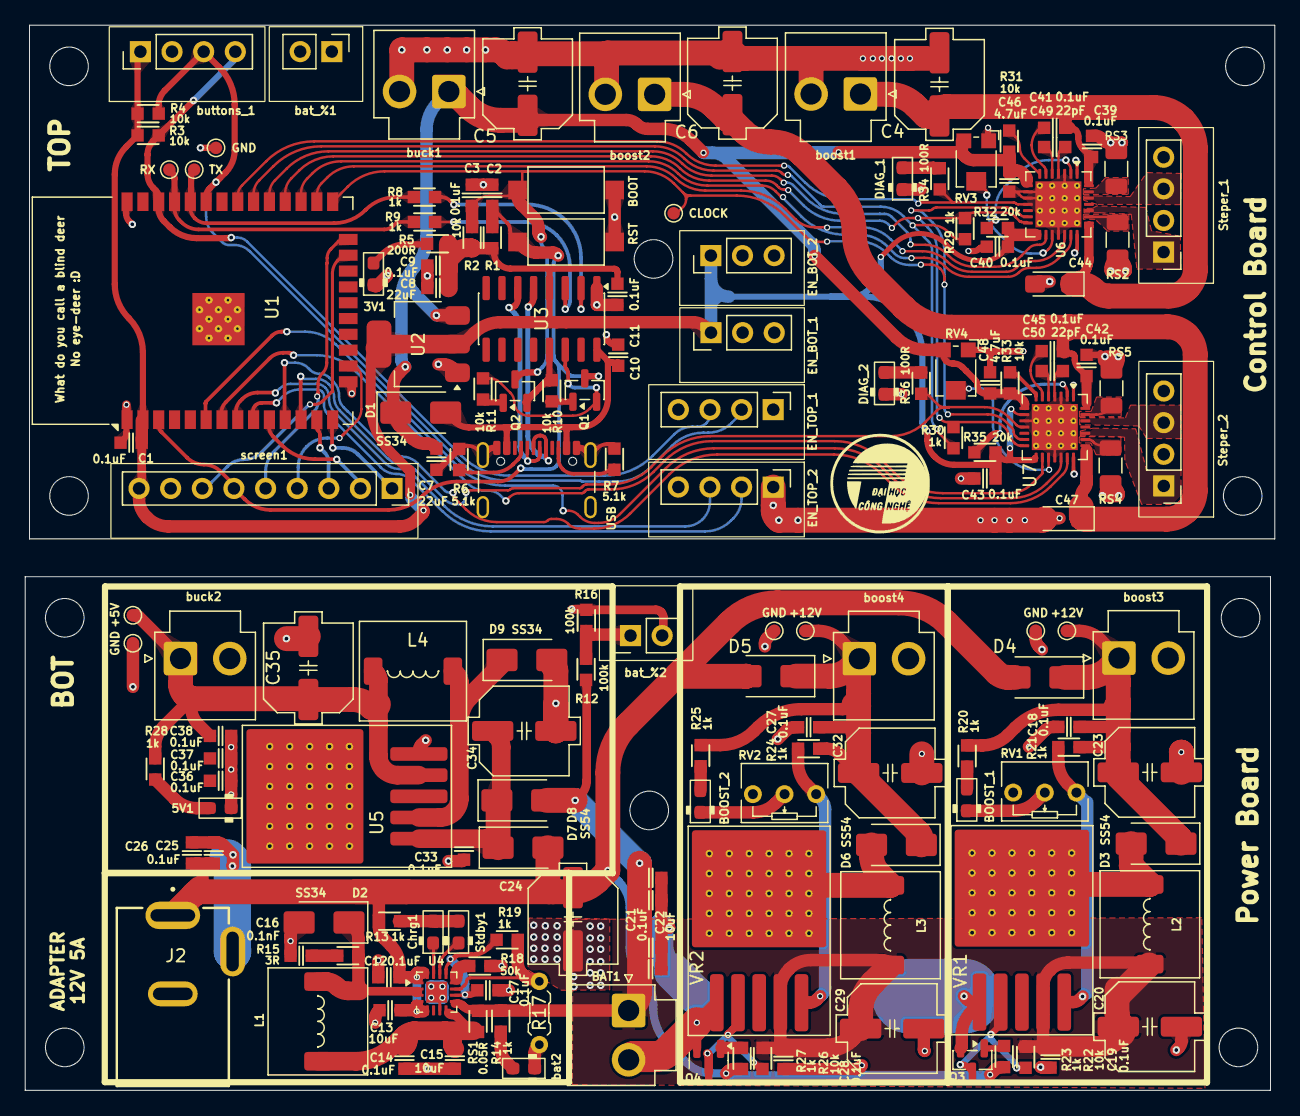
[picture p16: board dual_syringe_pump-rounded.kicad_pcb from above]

Board: 2 copper layers, 100.3 x 85.5 mm, 161 parts (0 on the bottom side), 94 nets.

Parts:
3V1, 5V1: LED; LED_0603_1608Metric_Pad1.05x0.95mm
+5V, +12V, +12V#2: TestPoint; TestPoint_Pad_D1.0mm
BAT1: Bat_protected; JST_VH_B2P-VH-B_1x02_P3.96mm_Vertical
BOOST_1, BOOST_2: LED; LED_0603_1608Metric_Pad1.05x0.95mm
BOOT: reset; SW_SPST_CK_RS282G05A3
C1, C2, C3, C9, C10, C11, C12, C14, C17, C18, C19, C21, C25, C26, C27, C28, C30, C33, C36, C37, C38, C39, C40, C41, C42, C43, C45: 0.1uF; C_0603
C4, C5, C6, C23, C24, C32, C34, C35: 100uF; C_Elec_6.3x7.7
C7, C8: 22uF; C_0603
C13, C15, C22, C31: 10uF; C_0603
C16: 0.1nF; C_0603
C20, C29: 330uF; C_Elec_6.3x7.7
C44, C47: 100uF; CP_EIA-3216-12_Kemet-S_HandSolder
C46, C48: 4.7uF; C_0603
C49, C50: 22pF; C_0603
CLOCK: TestPoint; TestPoint_Pad_D1.0mm
Chrg1: LED; LED_0603_1608Metric_Pad1.05x0.95mm
D1, D2, D9: SS34; D_SMA
D3, D4, D5, D6, D7, D8: SS54; D_SMA
DIAG_1, DIAG_2: LED; LED_0603_1608Metric_Pad1.05x0.95mm
EN_BOT_1, EN_BOT_2: Conn_01x03; PinHeader_1x03_P2.54mm_Vertical
EN_TOP_1, EN_TOP_2: Conn_01x04; PinHeader_1x04_P2.54mm_Vertical
GND: TestPoint; TestPoint_Pad_D1.0mm
GND#2, GND#3, GND#4: TestPoint; TestPoint_Pad_D1.0mm
J2: Barrel_Jack_Switch_Pin3Ring; GCT_DCJ200-10-A-XX-K_REVA
L1: 22uH; L_7.3x7.3_H4.5
L2, L3: 47uH; L_7.3x7.3_H4.5
L4: 33uH; L_7.3x7.3_H4.5
Q1, Q2, Q3, Q4: SS8050; SOT-23
R1, R2, R3, R4, R10, R11, R22, R26, R31, R33: 10k; R_0603
R5: 200R; R_0603
R6, R7: 5.1k; R_0603
R8, R9, R13, R14, R19, R20, R21, R23, R24, R25, R27, R28, R29, R30: 1k; R_0603
R12, R16: 100k; R_0603
R15: 3R; R_0603
R17: 47d 3950 (10K); R_Axial_DIN0204_L3.6mm_D1.6mm_P5.08mm_Horizontal
R18: 50k; R_0603
R32, R35: 20k; R_0603
R34, R36: 100R; R_0603
RS1: 0.05R; R_0603
RS2, RS3, RS4, RS5: 0.1R; R_1206_3216Metric
RST: boot; SW_SPST_CK_RS282G05A3
RV1, RV2: 10k; Potentiometer_Bourns_3266Y_Vertical
RV3, RV4: 20k; Potentiometer_Bourns_TC33X_Vertical
RX: TestPoint; TestPoint_Pad_D1.0mm
Stdby1: LED; LED_0603_1608Metric_Pad1.05x0.95mm
Steper_1, Steper_2: Conn_01x04; PinHeader_1x04_P2.54mm_Vertical
TX: TestPoint; TestPoint_Pad_D1.0mm
U1: ESP32-WROOM-32
U2: AMS1117-3.3; SOT-223-3_TabPin2
U3: CH340C; SOIC-16_3.9x9.9mm_P1.27mm
U4: TP5100; LQFN-16-1EP_3x3mm_P0.5mm_EP1.7x1.7mm
U5: LM2596S-buck; TO-263-5_TabPin3_ThermalVias
U6, U7: TMC2209-LA; VQFN-28-1EP_5x5mm_P0.5mm_EP3.7x3.7mm_ThermalVias
USB: USB_C_Receptacle_USB2.0_16P; USB_C_Receptacle_GCT_USB4105-xx-A_16P_TopMnt_Horizontal
VR1, VR2: XL6019; TO-263-5_TabPin6_ThermalVias
bat2: LED; LED_0603_1608Metric_Pad1.05x0.95mm
bat_%1, bat_%2: battery _percentage; PinHeader_1x02_P2.54mm_Vertical
boost1, boost3: boost_1; JST_VH_B2P-VH-B_1x02_P3.96mm_Vertical
boost2, boost4: boost_2; JST_VH_B2P-VH-B_1x02_P3.96mm_Vertical
buck1, buck2: buck; JST_VH_B2P-VH-B_1x02_P3.96mm_Vertical
buttons_1: Conn_01x04; PinHeader_1x04_P2.54mm_Vertical
screen1: Conn_01x09_Pin; PinSocket_1x09_P2.54mm_Vertical

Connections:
+3.3V: C1.1, C8.1, C9.1, C11.1, C40.2, C43.2, EN_BOT_1.1, EN_BOT_2.1, R1.1, R2.1, R3.1, R4.1, R5.2, R32.1, R35.1, U1.2 (VDD), U2.2 (VO), U3.4 (V3), U6.15 (VCC_IO), U7.9 (MS1/AD0), U7.15 (VCC_IO), buttons_1.1, screen1.9
+5V: +5V.1, C5.1, C7.1, C35.1, C36.1, C37.1, C38.1, C46.2, C48.2, D1.1 (K), L4.2, R28.2, R31.1, R33.1, RV3.3, RV4.3, U2.3 (VI), U5.4 (FB), U6.8 (5VOUT), U7.8 (5VOUT), buck1.1, buck2.1
+12V_1: +12V#2.1, C4.1, C18.1, C23.1, C39.1, C41.1, C44.1, D3.1 (K), D4.1 (K), R20.2, R21.2, U6.22 (VS), U6.28 (VS), boost1.1, boost3.1
+12V_2: +12V.1, C6.1, C27.1, C32.1, C42.1, C45.1, C47.1, D5.1 (K), D6.1 (K), R24.2, R25.2, U7.22 (VS), U7.28 (VS), boost2.1, boost4.1
/BACKLIGHT: U1.10 (IO25), screen1.2
/CS: U1.23 (IO15), screen1.7
/D+: U3.5 (UD+), USB.A6 (D+), USB.B6 (D+)
/D-: U3.6 (UD-), USB.A7 (D-), USB.B7 (D-)
/DC: U1.24 (IO2), screen1.5
/DTR: Q2.2 (E), R10.1, U3.13 (~DTR)
/MISO: U1.14 (IO12), screen1.1
/MOSI: U1.16 (IO13), screen1.4
/Power Circuits/NTC: R17.2 (-), R19.2, U4.11 (TS)
/Power Circuits/Vreg: C17.1, R19.1, U4.10 (VREG), U4.13 (CS)
/RST: Q1.2 (E), R11.2, U3.14 (~RTS)
/RX: R9.2, RX.1, U1.35 (TXD0/IO1)
/SCK: U1.13 (IO14), screen1.3
/SCL: EN_TOP_1.3, R3.2, U1.36 (IO22), buttons_1.4
/SCL1: EN_TOP_2.3, U1.8 (IO32)
/SDA: EN_TOP_1.2, R4.2, U1.33 (IO21), buttons_1.3
/SDA1: EN_TOP_2.2, U1.9 (IO33)
/TX: R8.2, TX.1, U1.34 (RXD0/IO3)
/esp_EN: C2.1, Q1.3 (C), R1.2, RST.1, U1.3 (EN), screen1.6
Adapter_+12V: C12.1, C13.1, C24.1, C25.1, C26.1, D4.2 (A), D5.2 (A), D7.2 (A), J2.1, R13.1, R23.2, R27.2, U4.1 (VIN), U4.4 (VIN), U4.5 (VIN), U4.16 (VIN)
DIAG_1: R34.2, U1.31 (IO19), U6.11 (DIAG)
DIAG_2: R36.2, U1.12 (IO27), U7.11 (DIAG)
DIR_1: U1.26 (IO4), U6.19 (DIR)
DIR_2: U1.6 (IO34), U7.19 (DIR)
EN_1: U1.27 (IO16), U6.20 (STDBY)
EN_2: U1.11 (IO26), U7.20 (STDBY)
GND: 5V1.1 (K), BAT1.2 (-), BOOST_1.1 (K), BOOST_2.1 (K), C12.2, C13.2, C14.2, C15.2, C16.2, C17.2, C18.2, C19.2, C20.2, C21.2, C22.2, C23.2, C24.2, C25.2, C26.2, C27.2, C28.2, C29.2, C30.2, C31.2, C32.2, C33.2, C34.2, C35.2, C36.2, C37.2, C38.2, D2.2 (A), D9.2 (A), GND#2.1, GND#3.1, GND#4.1, J2.2, J2.3, Q3.2 (E), Q4.2 (E), R16.2, R17.1 (+), R18.1, RV1.2, RV2.2, U4.7 (GND), U4.17 (EXP), U5.3 (GND), U5.5 (~ON/OFF), VR1.1 (GND), VR2.1 (GND), bat2.1 (K), bat_%2.2, boost3.2, boost4.2, buck2.2
GND1: 3V1.1 (K), BOOT.2, C1.2, C2.2, C3.2, C4.2, C5.2, C6.2, C7.2, C8.2, C9.2, C10.2, C11.2, C39.2, C40.1, C42.2, C43.1, C44.2, C46.1, C47.2, C48.1, DIAG_1.1 (K), DIAG_2.1 (K), EN_BOT_1.3, EN_BOT_2.3, EN_TOP_1.1, EN_TOP_2.1, GND.1, R6.1, R7.2, RS2.2, RS3.2, RS4.2, RS5.2, RST.2, RV3.1, RV4.1, U1.1 (GND), U1.15 (GND), U1.38 (GND), U1.39 (GND), U2.1 (GND), U3.1 (GND), U6.3 (GND), U6.9 (MS1/AD0), U6.10 (MS2/AD1), U6.18 (GND), U6.29 (GND), U7.3 (GND), U7.10 (MS2/AD1), U7.18 (GND), U7.29 (GND), USB.A1 (GND), USB.A12 (GND), USB.B1 (GND), USB.B12 (GND), USB.S1 (SHIELD), boost1.2, boost2.2, buck1.2, buttons_1.2, screen1.8
unnamed: 3V1.2 (A), R5.1
unnamed: 5V1.2 (A), R28.1
unnamed: BOOST_1.2 (A), R20.1
unnamed: BOOST_2.2 (A), R25.1
unnamed: C16.1, R15.1
unnamed: Chrg1.2 (A), R13.2, Stdby1.2 (A)
unnamed: Chrg1.1 (K), U4.15 (~CHRG)
unnamed: D2.1 (K), L1.1, R15.2, U4.2 (LX), U4.3 (LX)
unnamed: D3.2 (A), L2.2, VR1.3 (SW), VR1.6 (SW)
unnamed: D6.2 (A), L3.2, VR2.3 (SW), VR2.6 (SW)
unnamed: C33.1, C34.1, D7.1 (K), D8.1 (K), U5.1 (VIN)
unnamed: D9.1 (K), L4.1, U5.2 (OUT)
unnamed: DIAG_1.2 (A), R34.1
unnamed: DIAG_2.2 (A), R36.1
unnamed: R6.2, USB.A5 (CC1)
unnamed: R7.1, USB.B5 (CC2)
unnamed: Q1.1 (B), R10.2
unnamed: Q2.1 (B), R11.1
unnamed: Q3.1 (B), R23.1
unnamed: Q3.3 (C), R22.1, VR1.2 (EN)
unnamed: Q4.1 (B), R27.1
unnamed: Q4.3 (C), R26.1, VR2.2 (EN)
unnamed: Stdby1.1 (K), U4.14 (~STDBY)
unnamed: Steper_1.1, U6.24 (OA1)
unnamed: Steper_1.2, U6.21 (OA2)
unnamed: Steper_1.3, U6.26 (OB1)
unnamed: Steper_1.4, U6.1 (OB2)
unnamed: Steper_2.1, U7.24 (OA1)
unnamed: Steper_2.2, U7.21 (OA2)
unnamed: Steper_2.3, U7.26 (OB1)
unnamed: Steper_2.4, U7.1 (OB2)
unnamed: R9.1, U3.3 (RXD)
unnamed: R8.1, U3.2 (TXD)
unnamed: R18.2, U4.12 (RTRICK)
unnamed: C14.1, C15.1, L1.2, RS1.2, U4.8 (VS)
unnamed: RS2.1, U6.23 (BRA)
unnamed: RS3.1, U6.27 (BRB)
unnamed: C49.2, U6.5 (CPI)
unnamed: C49.1, U6.4 (CPO)
unnamed: R31.2, U6.7 (SPREAD)
unnamed: C41.2, U6.6 (VCP)
unnamed: RV3.2, U6.17 (VREF)
unnamed: R32.2, U6.2 (~EN)
unnamed: RS4.1, U7.23 (BRA)
unnamed: RS5.1, U7.27 (BRB)
unnamed: C50.2, U7.5 (CPI)
unnamed: C50.1, U7.4 (CPO)
unnamed: R33.2, U7.7 (SPREAD)
unnamed: C45.2, U7.6 (VCP)
unnamed: RV4.2, U7.17 (VREF)
unnamed: R35.2, U7.2 (~EN)
unnamed: R21.1, RV1.3, VR1.5 (FB)
unnamed: R24.1, RV2.3, VR2.5 (FB)
unnamed: R14.1, bat2.2 (A)
unnamed: R12.2, R16.1, bat_%2.1
RX_TMC: R29.2, R30.2, U1.28 (IO17), U6.14 (~PD/UART), U7.14 (~PD/UART)
STEP_1: U1.29 (IO5), U6.16 (STEP)
STEP_2: U1.7 (IO35), U7.16 (STEP)
TX_TMC: R29.1, R30.1, U1.30 (IO18)
USB_5V: C10.1, D1.2 (A), U3.16 (VCC), USB.A4 (VBUS), USB.A9 (VBUS), USB.B4 (VBUS), USB.B9 (VBUS)
Vbat: BAT1.1 (+), C19.1, C20.1, C21.1, C22.1, C28.1, C29.1, C30.1, C31.1, D8.2 (A), L2.1, L3.1, R12.1, R14.2, R22.2, R26.2, RS1.1, U4.9 (BAT), VR1.4 (VIN), VR2.4 (VIN)
esp32_CLK: BOOT.1, C3.1, CLOCK.1, Q2.3 (C), R2.2, U1.25 (IO0), U6.13 (CLK), U7.13 (CLK)

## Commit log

2026-02-22 Highlighted connectors
    [battery_charger.kicad_sch, dual_syringe_pump-rounded.kicad_pcb, dual_syringe_pump.kicad_sch]
2026-02-22 added pictures
    [stepper.kicad_sch]
2026-02-22 Enhance README with images and PCB layout section
    Updated README with additional images and modified project structure section.
2026-03-20 changed to mouse bites
    [battery_charger.kicad_sch, dual_syringe_pump.kicad_pcb, dual_syringe_pump.kicad_sch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]
2026-05-10 post production fixes
    [battery_charger.kicad_sch, dual_syringe_pump.kicad_pcb, dual_syringe_pump.kicad_sch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]
